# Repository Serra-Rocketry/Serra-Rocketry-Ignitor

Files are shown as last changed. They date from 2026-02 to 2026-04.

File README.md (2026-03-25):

# Serra Rocketry Ignitor




## Sobre
Sistema de ignição remota para foguetes experimentais da Serra Rocketry.

A solução é formada por duas estações independentes que se comunicam via LoRa 433 MHz:

1. Estação de Comando (operada pelo operador em distância segura)
2. Estação de Ignição (conectada fisicamente ao ignitor)

O objetivo é permitir ignição com redundância de segurança, confirmação de comunicação e feedback visual/sonoro durante toda a sequência.

## Arquitetura

### Estação de Comando
- Inicia a sequência de ignição por botão dedicado
- Exige ação mantida por 5 segundos
- Envia comando via LoRa e aguarda ACK
- Exibe status por LEDs e buzzer

### Estação de Ignição
- Recebe comando da estação de comando
- Executa contagem regressiva de 5 segundos
- Aborta se o comando for interrompido
- Aciona o ignitor ao fim da contagem

Para detalhes completos de pinagem, BOM, consumo, segurança e esquemáticos, consulte a documentação de hardware.

## Sequência de Ignição (Resumo)
1. Operador pressiona e mantém o botão de ignição por 5 s
2. Estação de comando envia `ARM` via LoRa
3. Estação de ignição confirma recebimento e inicia contagem
4. Se o botão for solto antes do fim, procedimento é abortado
5. Ao final de 5 s, a estação de ignição aciona o ignitor

## Componentes Principais
- 2x Raspberry Pi Pico
- 2x Módulos LoRa SX1278 (433 MHz)
- 2x LEDs amarelos e 2x LEDs vermelhos
- 2x Buzzers ativos
- 2x Botões liga/desliga
- 1x Botão de ignição momentâneo
- 1x Relé para acionamento do ignitor
- 2x Módulos TP4056 com proteção
- Baterias Li-ion/LiPo (capacidade em definição)
- Cases impressos em 3D

## Estrutura do Repositório
- `docs/`: documentação técnica e operacional
- `firmware/`: código embarcado e interface web local
- `hardware/`: esquemáticos, modelos, imagens e arquivos de fabricação
- `software/`: ferramentas de apoio de software
- `test/`: materiais de teste e validação

## Documentação
- [Hardware: arquitetura, BOM e pinagem](./hardware/README.md)
- [Instalação](./docs/INSTALACAO.md)
- [API e protocolos](./docs/API.md)
- [Testes](./docs/TESTES.md)
- [Troubleshooting](./docs/TROUBLESHOOTING.md)

## Segurança
- O botão de ignição deve ser momentâneo (sem trava)
- O comando de ignição deve permanecer ativo por toda a janela de 5 s
- Em perda de comunicação/heartbeat, o sistema deve abortar
- Testes devem ser feitos com carga dummy antes de ignição real
- Manter distância operacional segura entre operador e foguete

## Status do Projeto
- [x] Arquitetura macro de duas estações definida
- [x] BOM e pinagem iniciais documentados
- [ ] Firmware de comando e ignição finalizado
- [ ] Validação completa de comunicação LoRa
- [ ] Validação elétrica em bancada e campo
- [ ] Cases 3D finalizados para produção

## Contribuição
Consulte as diretrizes em [Boas Práticas Serra Rocketry](https://github.com/Serra-Rocketry/best-practices).

## Equipe
Projeto desenvolvido pela equipe Serra Rocketry.

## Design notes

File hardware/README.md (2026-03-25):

# Hardware - Serra Rocketry Ignitor

## Arquitetura do Sistema

O sistema é composto por **duas estações independentes** que se comunicam via rádio LoRa:

### 1. Estação de Comando
Operada remotamente pelo operador (distância segura do foguete).

**Função:**
- Iniciar sequência de ignição via botão dedicado
- Monitorar status da Estação de Ignição
- Fornecer feedback visual e sonoro ao operador

**Componentes:**
- 1x Raspberry Pi Pico
- 1x Módulo LoRa SX1278 433 MHz
- 1x Botão liga/desliga
- 1x Botão de ignição (ação mantida por 5 s)
- 2x LEDs: amarelo (conectado), vermelho (ignição iminente)
- 1x Buzzer ativo
- 1x Módulo TP4056 (com proteção) para recarregar a bateria
- 1x Bateria (a definir capacidade)
- Case impresso em 3D

### 2. Estação de Ignição
Conectada fisicamente ao ignitor do foguete.

**Função:**
- Receber comandos de ignição da Estação de Comando
- Executar contagem regressiva (5 s) com avisos sonoros
- Acionar o ignitor ao final da contagem
- Abortar procedimento se comando for interrompido

**Componentes:**
- 1x Raspberry Pi Pico
- 1x Módulo LoRa SX1278 433 MHz
- 2x LEDs: amarelo (conectado), vermelho (ignição iminente)
- 1x Buzzer ativo
- 1x Relé para acionamento do ignitor
- 1x Módulo TP4056 (com proteção) para recarregar a bateria
- 1x Bateria (a definir capacidade)
- Case impresso em 3D

## Lista de Componentes (BOM)

| Componente | Quantidade | Referência | Especificação | Link |
|---|---|---|---|---|
| Raspberry Pi Pico | 2 | MCU1, MCU2 | RP2040 | [Raspberry Pi](https://www.raspberrypi.com/products/raspberry-pi-pico/) |
| Módulo LoRa SX1278 | 2 | LORA1, LORA2 | 433 MHz | [Hoperf](https://www.hoperf.com/) |
| LED Amarelo 5mm | 2 | LED_Y1, LED_Y2 | 20 mA | - |
| LED Vermelho 5mm | 2 | LED_R1, LED_R2 | 20 mA | - |
| Buzzer ativo 5V | 2 | BZ1, BZ2 | Piezo | - |
| Botão Liga/Desliga | 2 | BTN_PWR1, BTN_PWR2 | 12V 20A | - |
| Botão de Ignição | 1 | BTN_IGN | 22mm, 3-9V (5V), Momentary Reset, Vermelho | - |
| Relé | 1 | K1 | Para ignitor (corrente a definir) | - |
| Bateria | 12 | BAT1, BAT2 | A definir (LiPo/18650) | - |
| Resistores 220Ω | 4 | R1-R4 | Para LEDs | - |
| Antena LoRa | 2 | ANT1, ANT2 | 433 MHz | - |
| Módulo TP4056 | 2 | CHG1, CHG2 | Carregador Li-ion/LiPo 1 célula (4,2 V), entrada 5 V, corrente de carga ajustável (até 1 A), proteção recomendada (DW01A+8205A) | - |

## Pinagem Raspberry Pi Pico

### Estação de Comando
| GPIO Pico | Conexão | Descrição |
|---|---|---|
| GP0 | LoRa SPI RX | SPI MISO |
| GP1 | LoRa SPI CS | Chip Select |
| GP2 | LoRa SPI SCK | SPI Clock |
| GP3 | LoRa SPI TX | SPI MOSI |
| GP4 | LoRa RESET | Reset |
| GP11 | LED Amarelo | Status: conectado |
| GP12 | LED Vermelho | Status: ignição iminente |
| GP13 | LED do botão | Status: ligado |
| GP19 | Buzzer | Alerta sonoro |
| GP14 | Botão Power | Liga/desliga |
| GP26 | Botão Ignição | Comando de ignição (segurar 5 s) |

### Estação de Ignição
| GPIO Pico | Conexão | Descrição |
|---|---|---|
| GP0 | LoRa SPI RX | SPI MISO |
| GP1 | LoRa SPI CS | Chip Select |
| GP2 | LoRa SPI SCK | SPI Clock |
| GP3 | LoRa SPI TX | SPI MOSI |
| GP4 | LoRa RESET | Reset |
| GP11 | LED Amarelo | Status: conectado com comando |
| GP12 | LED Vermelho | Status: ignição iminente |
| GP19 | Buzzer | Contagem regressiva |
| GP26 | Gate Ignitor | Comando Relé |

## Sequência de Operação

### Estados dos LEDs
| Estado | LED Amarelo | LED Vermelho |
|---|---|---|
| Desligado | OFF | OFF |
| Ligado (idle) | OFF | OFF |
| Conectado | ON | OFF |
| Ignição iminente | ON | PISCA |
| Ignição ativa | ON | ON |
| Erro | OFF | PISCA |

### Sequência de Ignição

1. **Operador pressiona botão de ignição na Estação de Comando**
   - Botão deve ser **mantido pressionado por 5 segundos**
   - LED vermelho começa a piscar
   - Buzzer emite tom contínuo

2. **Estação de Comando envia sinal LoRa para Estação de Ignição**
   - Pacote com comando `ARM`
   - Requer confirmação (ACK) da Estação de Ignição

3. **Estação de Ignição recebe comando e inicia contagem**
   - LED vermelho pisca rapidamente
   - Buzzer emite **5 apitos** (1 por segundo) = contagem regressiva
   - A cada segundo, verifica se comando ainda está ativo

4. **Durante a contagem (5 s):**
   - Se botão na Estação de Comando for **solto**: abortado
   - Estação de Ignição envia mensagem de abort
   - Ambas as estações voltam ao estado "Conectado"

5. **Ao final dos 5 segundos:**
   - LED vermelho fica **sólido** em ambas estações
   - Estação de Ignição aciona o ignitor (GPIO16 HIGH)
   - Buzzer emite tom longo de confirmação

6. **Após ignição:**
   - Sistema aguarda 3 s e retorna ao estado "Conectado"

## Segurança

- Botão de ignição deve ser do tipo **momentâneo** (não trava)
- Ignição só ocorre se comando for mantido por toda a sequência (5 s)
- Comunicação LoRa bidirecional: Estação de Ignição confirma recebimento
- Timeout: se Estação de Ignição não receber heartbeat por 2 s, aborta
- Sensor de continuidade (opcional): verifica se ignitor está conectado antes de armar

## Consumo de Energia

**Estimativas iniciais (a validar):**
- Operação normal (conectado): ~50 mA @ 3.3 V
- Transmissão LoRa: ~120 mA (picos)
- Autonomia estimada: 6-8 h com bateria 1000 mAh

### Carregamento com TP4056

- Cada estação usa um TP4056 dedicado (CHG1 e CHG2) para 2 células Li-ion/LiPo (3,7 V nominal).
- Conexão típica: `IN+ / IN-` (5 V da porta USB), `BAT+ / BAT-` (bateria), `OUT+ / OUT-` (alimentação da carga) quando a placa tiver proteção integrada.
- Corrente de carga recomendada para bateria de 1000 mAh: 0,5 A a 1,0 A (0,5C a 1C), respeitando especificação da bateria.
- Preferir módulos com proteção (DW01A + 8205A) para reduzir risco de sobrecarga, descarga profunda e curto.

## Galeria de Componentes

### Raspberry Pi Pico
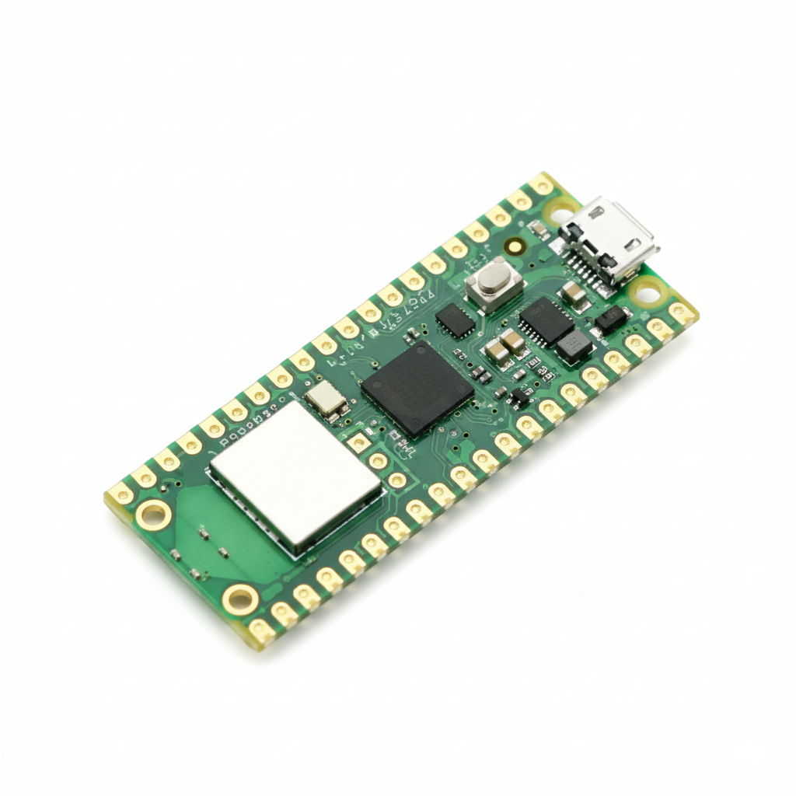
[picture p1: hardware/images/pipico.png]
Raspberry Pi Pico


Microcontrolador dual-core ARM Cortex-M0+ (RP2040), 264KB SRAM, 2MB Flash.

### Módulo LoRa SX1268
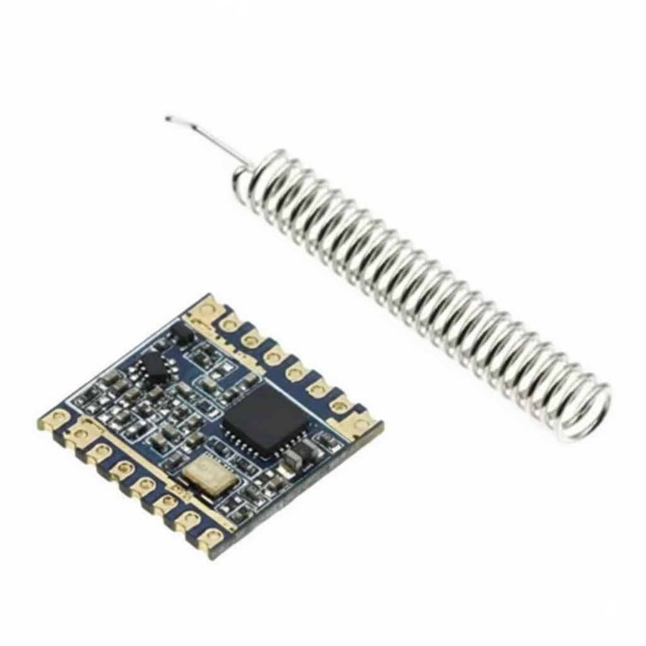
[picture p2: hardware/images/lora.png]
Módulo LoRa SX1268


Transceptor LoRa de longo alcance operando em **433 MHz**. Chip Semtech SX1268.

### Botão Liga/Desliga
Botão Liga/Desliga

Botão de potência **12V 20A** para controle de energia das estações.

### Botão de Ignição

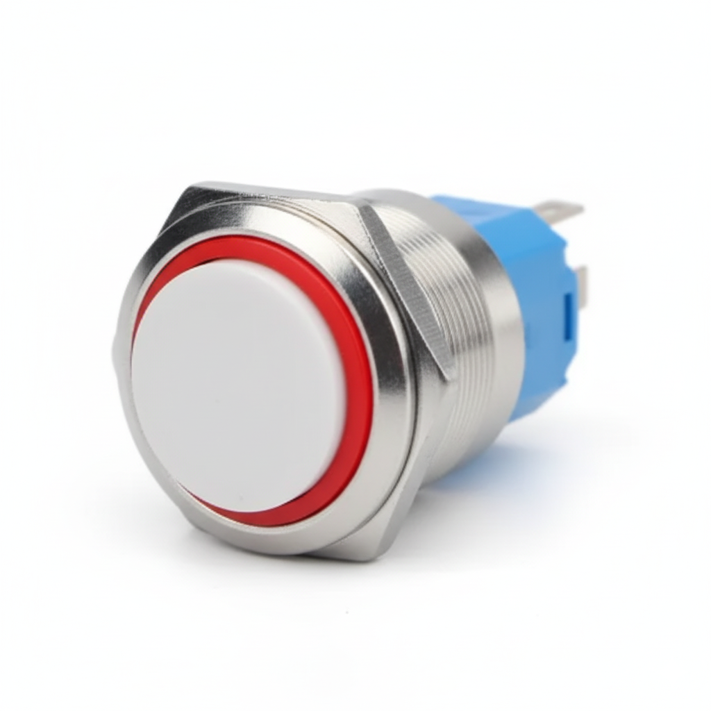
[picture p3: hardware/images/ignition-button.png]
Botão de Ignição


Botão momentâneo (Momentary Reset), **22mm**, vermelho, **3-9V (5V)**. Usado exclusivamente na Estação de Comando para iniciar a sequência de ignição.

## Esquemáticos

### Estação de comando

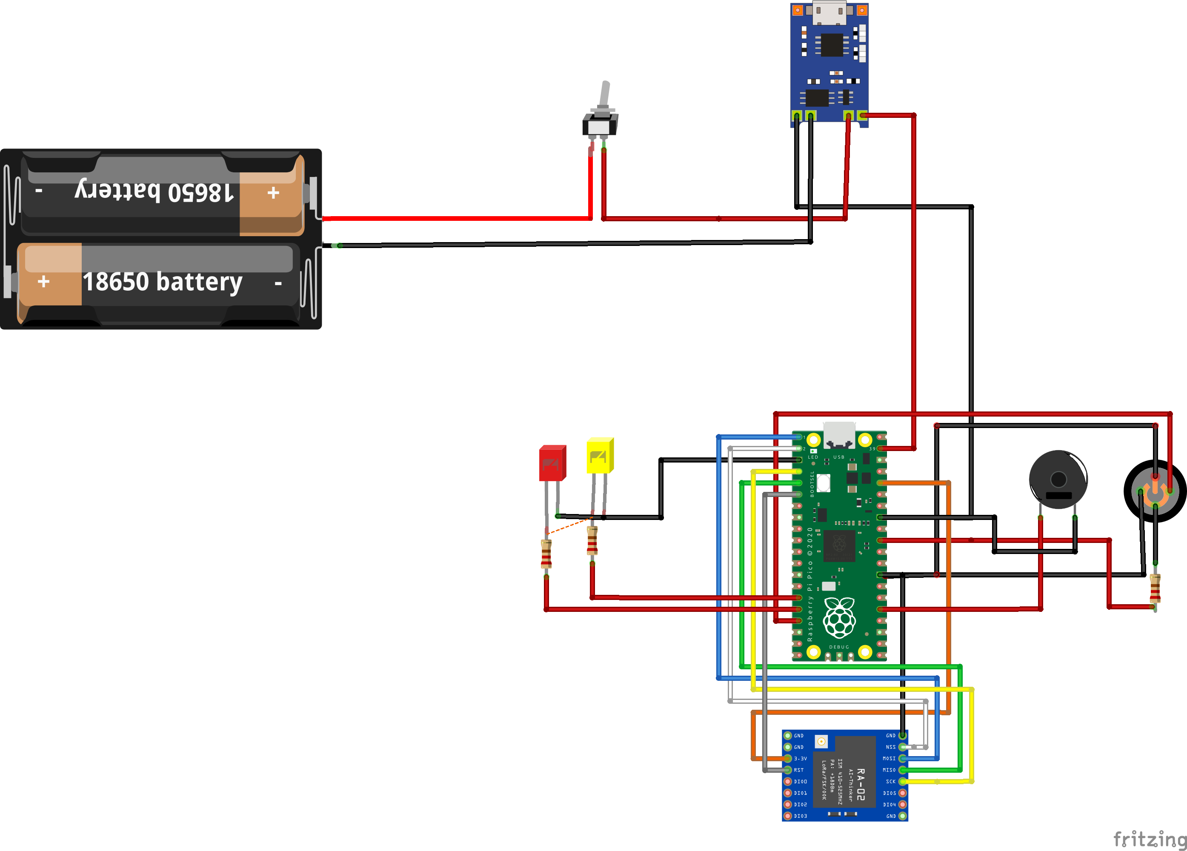
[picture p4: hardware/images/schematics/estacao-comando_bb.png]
Esquemático fritzing, caixa de comando


### Estação de ignicão

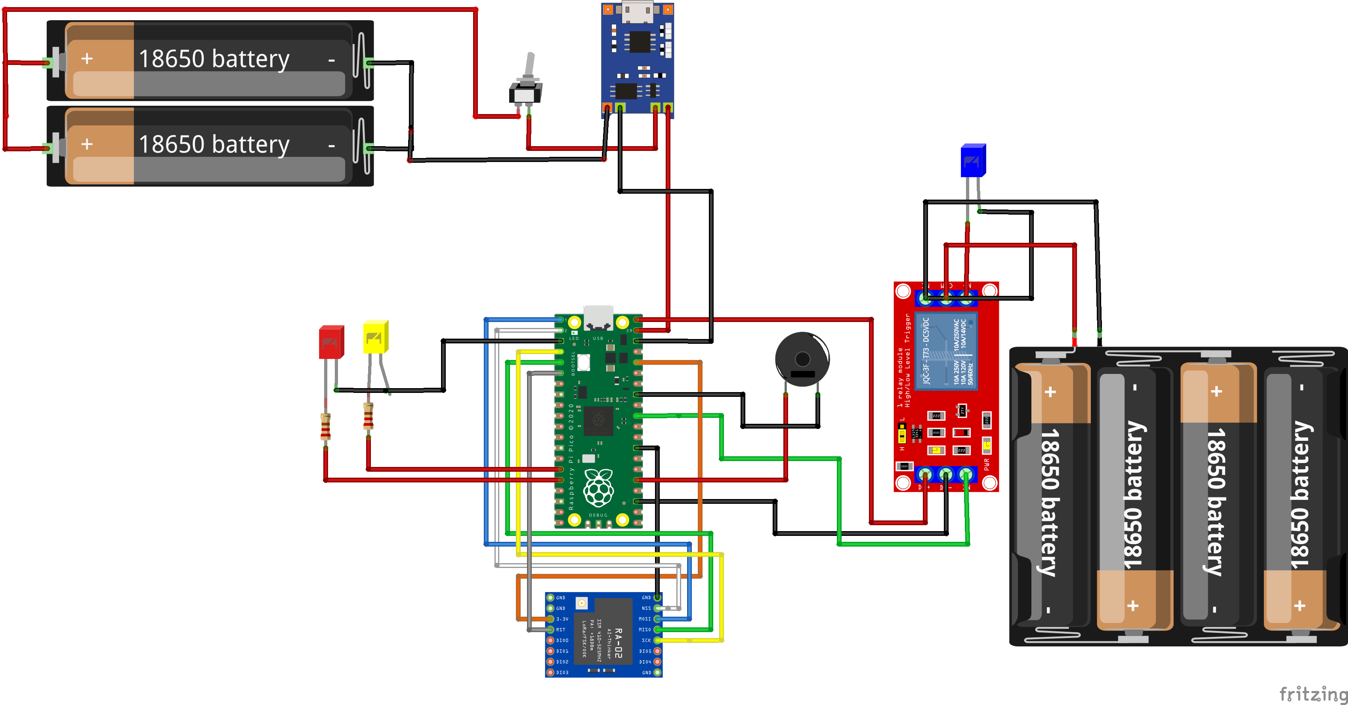
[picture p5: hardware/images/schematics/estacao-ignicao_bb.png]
Esquemático fritzing, caixa de ignição


## Arquivos de Fabricação

- [Modelos 3D dos cases](./3d_models/) - *A criar*

## Notas Importantes

- **Sempre conectar antena LoRa antes de energizar** (dano ao módulo)
- Isolar circuito do ignitor via relé
- Testar sequência completa com carga dummy (lâmpada) antes de uso real
- Manter distância mínima de 10 m entre operador e foguete

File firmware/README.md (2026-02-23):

# Firmware - Serra Rocketry Ignitor

## Visão Geral

O firmware é desenvolvido em **MicroPython** para Raspberry Pi Pico. Existem dois programas principais:
- `command_station.py` - Firmware da Estação de Comando
- `ignition_station.py` - Firmware da Estação de Ignição

## Arquitetura

### Estação de Comando

**Máquina de Estados:**
1. **IDLE** - Sistema ligado, aguardando conexão
2. **CONNECTED** - Heartbeat estabelecido com Estação de Ignição
3. **ARMING** - Botão de ignição pressionado, enviando comandos ARM
4. **IGNITION** - Ignição confirmada pela Estação de Ignição
5. **ERROR** - Erro de comunicação ou timeout

**Responsabilidades:**
- Enviar `HEARTBEAT` a cada 1 s
- Monitorar botão de ignição (GP15)
- Enviar sequência `ARM_ACTIVE` com contadores 5→0
- Enviar `ABORT` se botão for solto prematuramente
- Atualizar LEDs e buzzer conforme estado

### Estação de Ignição

**Máquina de Estados:**
1. **IDLE** - Sistema ligado, aguardando conexão
2. **CONNECTED** - Recebendo heartbeats da Estação de Comando
3. **ARMED** - Recebendo comandos ARM, executando contagem regressiva
4. **IGNITION** - Acionando ignitor (GP16 HIGH)
5. **ERROR** - Timeout de comunicação ou falha de hardware

**Responsabilidades:**
- Responder `HEARTBEAT_ACK` aos heartbeats
- Validar sequência de comandos `ARM_ACTIVE`
- Executar contagem regressiva com apitos
- Acionar ignitor (GP16) ao receber `ARM_ACTIVE(0)`
- Abortar se não receber heartbeat por 2 s

## Configuração

### 1. Copiar Template

```bash
cp firmware/config.example.h firmware/config.h
```

### 2. Ajustar Parâmetros

Editar `config.h`:

```python
# Identificação da estação
STATION_TYPE = "COMMAND"  # ou "IGNITION"
STATION_ID = 0x01

# LoRa
LORA_FREQ = 915.0  # MHz
LORA_BANDWIDTH = 125000  # Hz
LORA_SPREADING_FACTOR = 7  # 7-12 (maior = mais alcance, menor velocidade)
LORA_TX_POWER = 20  # dBm

# Timeouts
HEARTBEAT_INTERVAL = 1.0  # segundos
HEARTBEAT_TIMEOUT = 2.0   # segundos
ARM_INTERVAL = 1.0        # segundos (1 por segundo na contagem)

# GPIOs
PIN_LED_GREEN = 10
PIN_LED_YELLOW = 11
PIN_LED_RED = 12
PIN_BUZZER = 13
PIN_BUTTON_POWER = 14
PIN_BUTTON_IGNITION = 15  # apenas Estação de Comando
PIN_IGNITOR_GATE = 16     # apenas Estação de Ignição
```

## Estrutura do Código

```
firmware/
├── config.example.h       # Template de configuração
├── config.h               # Configuração local (gitignored)
├── lib/
│   ├── lora.py           # Driver LoRa (SX1276/SX1278)
│   ├── protocol.py       # Codificação/decodificação de pacotes
│   └── state_machine.py  # Lógica de estados
├── command_station.py     # Firmware Estação de Comando
└── ignition_station.py    # Firmware Estação de Ignição
```

## Fluxo de Dados

### Estação de Comando

```
main loop (100 Hz):
  1. Ler botão de ignição (GP15)
  2. Se pressionado e CONNECTED:
       - Entrar em ARMING
       - Enviar ARM_ACTIVE(counter)
       - Decrementar counter a cada 1 s
  3. Se solto durante ARMING:
       - Enviar ABORT
       - Voltar para CONNECTED
  4. A cada 1 s:
       - Enviar HEARTBEAT
       - Atualizar LEDs conforme estado
  5. Processar respostas do LoRa
```

### Estação de Ignição

```
main loop (100 Hz):
  1. Receber pacotes LoRa
  2. Se HEARTBEAT recebido:
       - Responder HEARTBEAT_ACK
       - Resetar timer de timeout
  3. Se ARM_ACTIVE recebido:
       - Validar contador sequencial
       - Emitir apito do buzzer
       - Atualizar LED vermelho (piscar)
  4. Se ARM_ACTIVE(0) recebido:
       - Acionar GP16 HIGH (ignitor)
       - LED vermelho sólido
       - Buzzer tom longo
  5. Se timeout (2 s sem HEARTBEAT):
       - Abortar, entrar em ERROR
       - LED vermelho pisca rápido
  6. Atualizar LEDs/buzzer conforme estado
```

## Comandos e Protocolos

Ver documentação completa em `docs/API.md`.

**Mensagens principais:**
- `HEARTBEAT` (0x10) - Comando → Ignição
- `HEARTBEAT_ACK` (0x11) - Ignição → Comando
- `ARM_ACTIVE(N)` (0x21) - Comando → Ignição, N = 5..0
- `ABORT` (0x22) - Comando → Ignição
- `STATUS_ARMED(N)` (0x42) - Ignição → Comando

## Build e Deploy

### Usando Thonny IDE

1. Conectar Raspberry Pi Pico via USB (segurar BOOTSEL)
2. Instalar MicroPython via Thonny (Tools → Options → Interpreter)
3. Carregar bibliotecas:
   - File → Save as → Raspberry Pi Pico → `lib/lora.py`
   - Repetir para `protocol.py` e `state_machine.py`
4. Carregar firmware principal:
   - Abrir `command_station.py` (ou `ignition_station.py`)
   - File → Save as → Raspberry Pi Pico → `main.py`
5. Desconectar e reconectar Pico (sem BOOTSEL) - deve executar automaticamente

### Usando ampy (linha de comando)

```bash
# Instalar ampy
pip install adafruit-ampy

# Upload de bibliotecas
ampy --port /dev/ttyACM0 mkdir lib
ampy --port /dev/ttyACM0 put lib/lora.py lib/lora.py
ampy --port /dev/ttyACM0 put lib/protocol.py lib/protocol.py
ampy --port /dev/ttyACM0 put lib/state_machine.py lib/state_machine.py

# Upload firmware (Estação de Comando)
ampy --port /dev/ttyACM0 put command_station.py main.py

# Upload firmware (Estação de Ignição)
ampy --port /dev/ttyACM1 put ignition_station.py main.py
```

## Debug via Serial

Conectar monitor serial (115200 baud) para ver logs:

```bash
screen /dev/ttyACM0 115200
# ou
minicom -D /dev/ttyACM0 -b 115200
```

**Mensagens esperadas:**
```
[COMMAND] Boot OK
[COMMAND] LoRa init: 915.0 MHz
[COMMAND] State: IDLE
[COMMAND] -> HEARTBEAT
[COMMAND] <- HEARTBEAT_ACK (RSSI: -45)
[COMMAND] State: CONNECTED
[COMMAND] Button pressed, starting ARM
[COMMAND] -> ARM_ACTIVE(5)
[COMMAND] <- STATUS_ARMED(5)
...
[COMMAND] -> ARM_ACTIVE(0)
[COMMAND] <- STATUS_IGNITION
[COMMAND] State: IGNITION
```

## Testes

### Teste Unitário (sem hardware)

```bash
cd firmware
python -m pytest tests/
```

### Teste de Integração (com hardware)

Ver `test/README.md` para procedimentos completos.

## Segurança no Código

- **Watchdog timer:** Reinicia Pico se main loop travar
- **Validação de CRC:** Todo pacote LoRa é verificado antes de processar
- **Timeout rígido:** Estação de Ignição aborta se não receber heartbeat por 2 s
- **Sequência monotônica:** Contador ARM_ACTIVE deve ser decrescente e sequencial (5→4→3→2→1→0)

## Próximas Implementações

- [ ] Criptografia AES-128 nos pacotes LoRa
- [ ] Sensor de continuidade do ignitor (GP17)
- [ ] Log em flash interno (últimas 10 ignições)
- [ ] Modo de diagnóstico via serial
- [ ] Over-the-air (OTA) update via LoRa

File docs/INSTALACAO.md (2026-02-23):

# Guia de Instalação Detalhado

## Visão Geral

Este guia orienta a montagem das duas estações do sistema de ignição:
- **Estação de Comando** (operada remotamente)
- **Estação de Ignição** (conectada ao foguete)

## 1. Pré-requisitos de Ambiente

### Software
- Python 3.8+ (`pip install -r requirements.txt`)
- Thonny IDE (recomendado para Raspberry Pi Pico) ou VS Code com extensão MicroPython
- Ferramenta de flash: `picotool` ou via Thonny

### Hardware
- Multímetro para verificação de continuidade
- Fonte de bancada 3.3-5 V ou baterias
- Ferro de solda (montagem em protoboard ou PCB)

## 2. Clonar e Preparar

```bash
git clone https://github.com/Serra-Rocketry/Serra-Rocketry-Ignitor.git
cd Serra-Rocketry-Ignitor
pip install -r requirements.txt
```

## 3. Montagem de Hardware

### 3.1. Estação de Comando

**Componentes necessários:**
- 1x Raspberry Pi Pico
- 1x Módulo LoRa 915 MHz
- 3x LEDs (verde, amarelo, vermelho) + 3x resistores 220Ω
- 1x Buzzer ativo 5V
- 2x Botões tácteis (power, ignição)
- Bateria e regulador (se necessário)

**Conexões:** Ver pinagem detalhada em `hardware/README.md`.

**Checklist:**
1. Soldar headers no Raspberry Pi Pico (se necessário)
2. Conectar módulo LoRa via SPI (GP0-GP4)
3. Conectar LEDs aos GPIOs 10-12 com resistores
4. Conectar buzzer ao GP13
5. Conectar botões aos GP14 (power) e GP15 (ignição) com pull-down
6. Fixar antena no módulo LoRa **antes** de energizar
7. Conectar bateria/fonte

### 3.2. Estação de Ignição

**Componentes necessários:**
- 1x Raspberry Pi Pico
- 1x Módulo LoRa 915 MHz
- 3x LEDs (verde, amarelo, vermelho) + 3x resistores 220Ω
- 1x Buzzer ativo 5V
- 1x MOSFET ou relé para ignitor
- Bateria e regulador (se necessário)

**Conexões:** Ver pinagem detalhada em `hardware/README.md`.

**Checklist:**
1. Soldar headers no Raspberry Pi Pico
2. Conectar módulo LoRa via SPI (GP0-GP4)
3. Conectar LEDs aos GPIOs 10-12 com resistores
4. Conectar buzzer ao GP13
5. Conectar MOSFET/relé ao GP16 (gate do ignitor)
6. Isolar circuito do ignitor com diodo flyback (se usar relé)
7. Fixar antena no módulo LoRa **antes** de energizar
8. Conectar bateria/fonte

### 3.3. Teste de Continuidade

Antes de energizar:
- Verificar curto-circuitos com multímetro
- Confirmar polaridade da bateria
- Verificar que antenas estão conectadas

## 4. Configuração do Firmware

### 4.1. Copiar Configuração

```bash
cp firmware/config.example.h firmware/config.h
```

Editar `config.h` e ajustar:
- `LORA_FREQ` → 915.0 (MHz)
- `STATION_TYPE` → `COMMAND` ou `IGNITION`
- IDs únicos para cada estação

### 4.2. Compilar e Gravar

#### Usando Thonny:
1. Abrir Thonny IDE
2. Conectar Raspberry Pi Pico via USB (segurar BOOTSEL ao conectar)
3. Instalar MicroPython: Tools → Options → Interpreter → Install or update MicroPython
4. Abrir `firmware/main.py` (Estação de Comando ou Ignição)
5. Clicar em Run → Save to Raspberry Pi Pico
6. Repetir para a outra estação

#### Usando linha de comando:
```bash
cd firmware
# Para Estação de Comando
ampy --port /dev/ttyACM0 put command_station.py main.py

# Para Estação de Ignição
ampy --port /dev/ttyACM1 put ignition_station.py main.py
```

## 5. Validar Operação

### 5.1. Teste Inicial (sem ignitor)

1. Energizar **apenas** a Estação de Comando
   - LED verde deve acender
   - LED amarelo permanece apagado (sem conexão)

2. Energizar a Estação de Ignição
   - LED verde acende em ambas
   - Após 1-2 s, LEDs amarelos acendem (heartbeat estabelecido)
   - Monitor serial mostra mensagens `HEARTBEAT` e `HEARTBEAT_ACK`

3. Testar sequência de ignição (com carga dummy)
   - Conectar LED/lâmpada ao GP16 da Estação de Ignição
   - Pressionar e segurar botão de ignição na Estação de Comando
   - Observar: LEDs vermelhos piscam, buzzer emite 5 apitos
   - Ao final, LED/lâmpada conectada ao GP16 acende

### 5.2. Teste de Abort

1. Iniciar sequência de ignição
2. Soltar botão após 2-3 segundos
3. Confirmar que carga dummy **não** aciona

### 5.3. Teste de Alcance

1. Posicionar estações a 50 m de distância (LOS)
2. Confirmar LEDs amarelos permanecem acesos
3. Executar sequência completa de ignição
4. Se sucesso, aumentar distância gradualmente

## 6. Montagem nos Cases 3D

1. Imprimir cases: `hardware/3d_models/case_command.stl` e `case_ignition.stl`
2. Fixar componentes com parafusos M3 ou cola quente
3. Garantir que antenas ficam externas ao case
4. Posicionar LEDs e botões nos furos frontais

## 7. Integração com Ignitor Real

⚠️ **ATENÇÃO: Realizar apenas em local seguro e com supervisão!**

1. Conectar ignitor aos terminais da Estação de Ignição (saída do MOSFET/relé)
2. Confirmar continuidade com multímetro
3. Posicionar Estação de Ignição junto ao foguete (≥ 10 m de distância)
4. Operador permanece com Estação de Comando em posição segura
5. Executar sequência de ignição conforme procedimento operacional

## 8. Troubleshooting Inicial

| Problema | Possível Causa | Solução |
|---|---|---|
| LED verde não acende | Sem alimentação | Verificar bateria/fonte |
| LED amarelo não acende | LoRa não comunica | Confirmar antenas, frequência, conexões SPI |
| Buzzer não soa | GPIO mal conectado | Verificar GP13, trocar buzzer |
| Ignitor não aciona | MOSFET/relé com problema | Testar GP16 com LED, verificar gate driver |

Ver mais em `docs/TROUBLESHOOTING.md`.

## 9. Próximos Passos

- Executar plano de testes completo: `test/README.md`
- Registrar resultados em `docs/TESTES.md`
- Calibrar alcance LoRa conforme necessidade
- Imprimir cases finais após validação

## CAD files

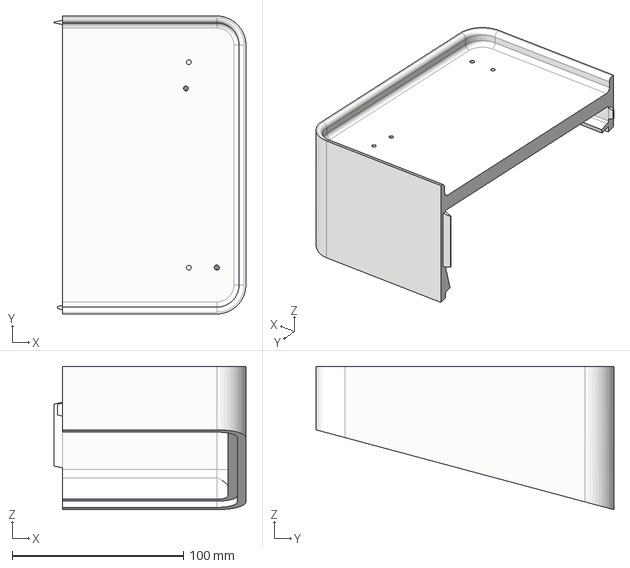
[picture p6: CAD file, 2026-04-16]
hardware/3d_models/comando/lado1.step
112.0 x 174.0 x 83.7 mm

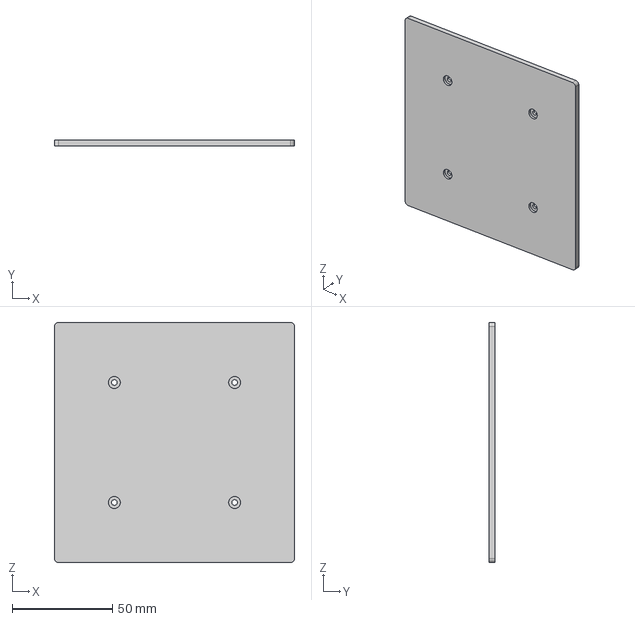
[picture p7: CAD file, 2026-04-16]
hardware/3d_models/ignição/TAMPABAIXO.step
120.0 x 3.00 x 120.0 mm

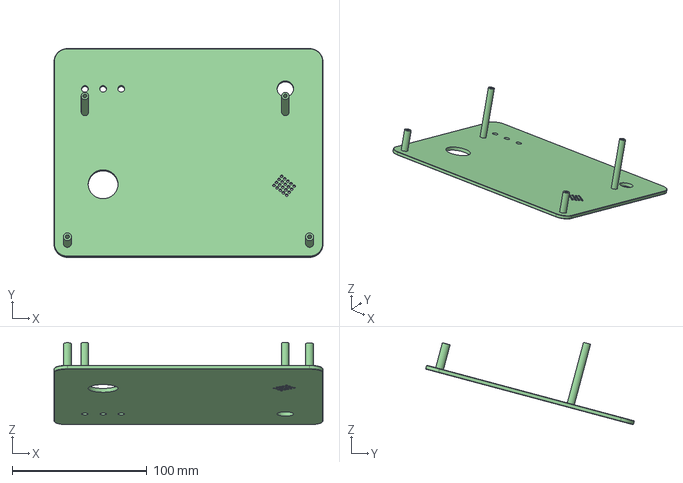
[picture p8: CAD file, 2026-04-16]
hardware/3d_models/comando/tampacima.step
200.0 x 155.2 x 61.2 mm
caixa
Componente3

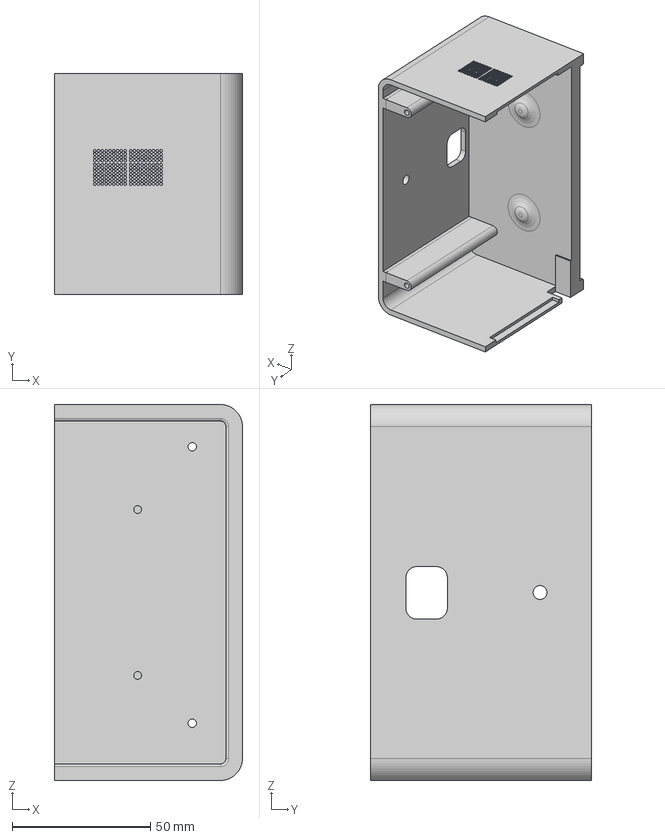
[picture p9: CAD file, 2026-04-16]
hardware/3d_models/ignição/caixapart2.step
68.0 x 80.0 x 136.0 mm

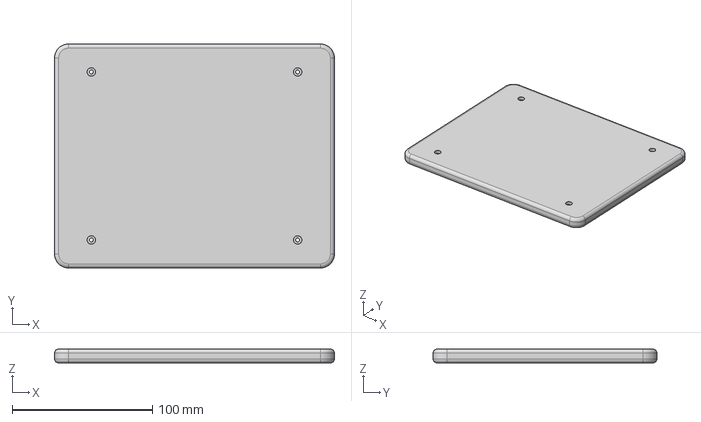
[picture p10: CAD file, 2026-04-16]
hardware/3d_models/comando/tampabaixo.step
200.0 x 160.0 x 10.0 mm

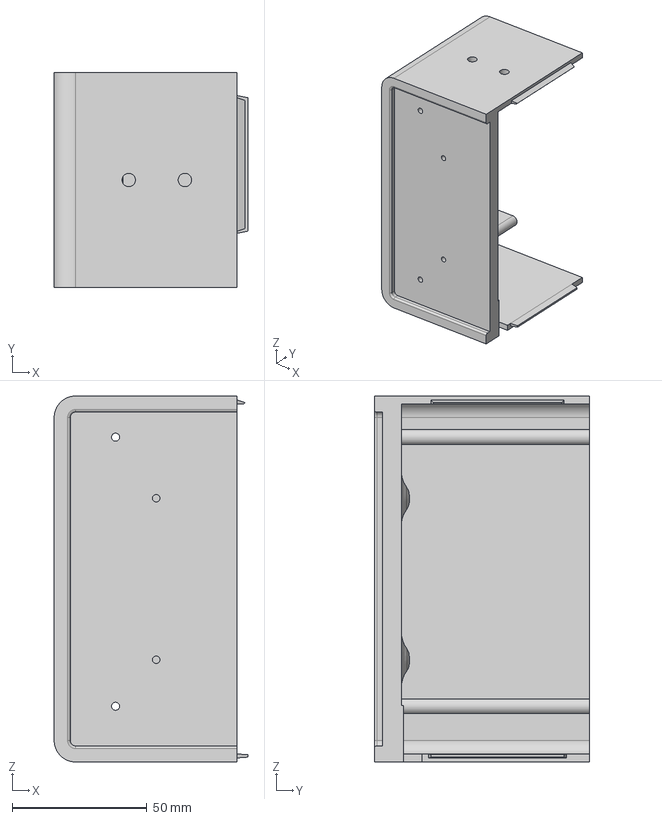
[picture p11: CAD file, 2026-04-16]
hardware/3d_models/ignição/caixapart1.step
72.0 x 80.0 x 136.0 mm

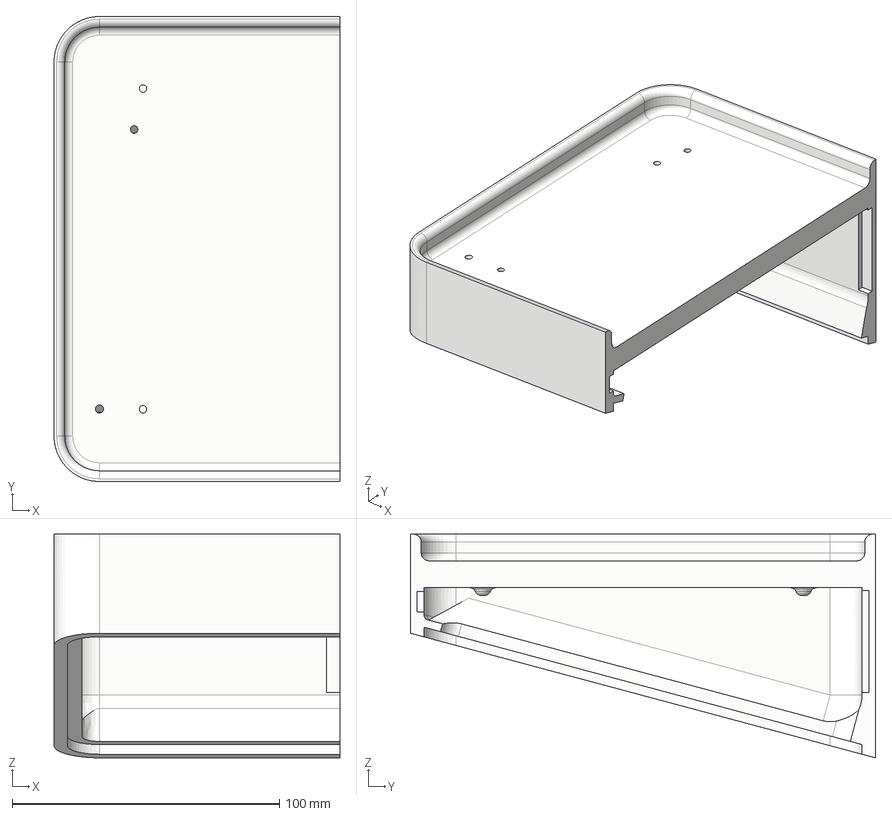
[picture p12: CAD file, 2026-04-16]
hardware/3d_models/comando/lado2.step
107.0 x 174.0 x 83.7 mm

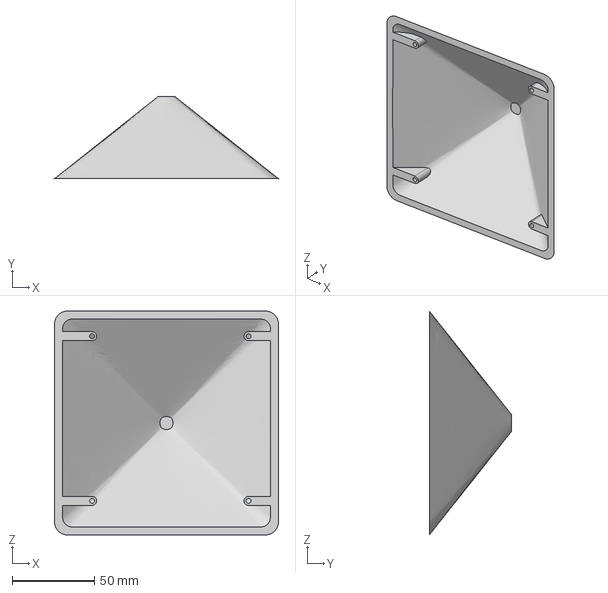
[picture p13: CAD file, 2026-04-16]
hardware/3d_models/ignição/TAMPACIMA.step
136.0 x 50.0 x 136.0 mm

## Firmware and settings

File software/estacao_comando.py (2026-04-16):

"""
╔══════════════════════════════════════════════════════════════════╗
║         ESTAÇÃO DE COMANDO — SISTEMA DE IGNIÇÃO LoRa             ║
║  Arquivo  : command_station.py                                   ║
║  Hardware : Raspberry Pi Pico + SX1278 (433 MHz)                 ║
║  Autor    : Sistema de Ignição de Foguetes                       ║
╚══════════════════════════════════════════════════════════════════╝

PINAGEM — SX1278 → Raspberry Pi Pico
─────────────────────────────────────
  SX1278   │ Pico GPIO │ Pino físico
  ─────────┼───────────┼────────────
  MOSI     │ GP3      │ 5
  MISO     │ GP0      │ 1
  SCK      │ GP2      │ 4
  NSS/CS   │ GP1      │ 2
  RESET    │ GP4      │ 6
  DIO0/G0  │ GP15      │ 20


PERIFÉRICOS
─────────────────────────────────────
  LED Amarelo → GP11  (pino 15)   + resistor 330Ω → GND
  LED Vermelho→ GP12  (pino 16)   + resistor 330Ω → GND
  Buzzer      → GP19  (pino 25)   + resistor 100Ω → GND
  Botão       → GP26  (pino 31)   → GND  (pull-up interno ativado)
"""

from machine import Pin, SPI
import utime

# ─────────────────────────────────────────────────────────────────
#  DEPENDÊNCIA: driver SX127x para MicroPython
#  Instale copiando sx127x.py para o Pico via Thonny ou mpremote.
#  Repositório: https://github.com/Serra-Rocketry/ignitor
#  ou instale via: mpremote mip install github:Wei1234c/SX127x_driver
# ─────────────────────────────────────────────────────────────────
try:
    from sx127x import SX127x
    LORA_AVAILABLE = True
except ImportError:
    # Modo de desenvolvimento sem hardware LoRa
    LORA_AVAILABLE = False
    print("[WARN] sx127x não encontrado — rodando sem LoRa real.")


# ╔══════════════════════════════════════════════════════════════╗
# ║                     CONFIGURAÇÕES                           ║
# ╚══════════════════════════════════════════════════════════════╝

# ── Pinos SPI / LoRa ─────────────────────────────────────────────
PIN_MOSI  = 5
PIN_MISO  = 1
PIN_SCK   = 4
PIN_CS    = 2
PIN_RESET = 6
PIN_DIO0  = 20

# ── Periféricos ──────────────────────────────────────────────────
PIN_LED_YELLOW = 15  # pisca durante o arme
PIN_LED_RED    = 16  # acende fixo ao receber ACK
PIN_BUZZER     = 25  # bipes de alerta
PIN_BUTTON     = 31  # botão momentâneo (active-low, pull-up)

# ── Tempos (ms) ──────────────────────────────────────────────────
HOLD_REQUIRED_MS   = 5_000   # tempo que o botão deve ficar pressionado
DEBOUNCE_MS        = 50      # janela de debounce
BLINK_INTERVAL_MS  = 250     # cadência do LED amarelo / buzzer
ACK_TIMEOUT_MS     = 2_000   # aguarda ACK por este tempo após ARM_CONFIRMED
RETRANSMIT_MS      = 200     # intervalo entre re-envios do ARM_CONFIRMED

# ── Mensagens LoRa ───────────────────────────────────────────────
MSG_ARM    = "ARM_CONFIRMED"
MSG_ABORT  = "ABORT"
MSG_ACK    = "ACK"

# ── Parâmetros LoRa (SX1278 @ 433 MHz) ──────────────────────────
LORA_PARAMS = {
    "frequency"         : 433e6,
    "bandwidth"         : 125e3,
    "spreading_factor"  : 7,
    "coding_rate"       : 5,        # 4/5
    "output_power"      : 17,       # dBm (máx 20)
    "rx_crc"            : True,
}


# ╔══════════════════════════════════════════════════════════════╗
# ║                    ESTADOS DA MÁQUINA                       ║
# ╚══════════════════════════════════════════════════════════════╝
class State:
    # Estado inicial: aguardando a pressão do botão de ignição.
    IDLE        = "IDLE"
    # Estado de armamento: o botão está pressionado e o sistema conta 5 segundos.
    ARMING      = "ARMING"
    # Estado de transmissão: envia repetidamente o comando de armamento.
    TRANSMITTING = "TRANSMITTING"
    # Estado de confirmação: ACK recebido do receptor, ignição confirmada.
    CONFIRMED   = "CONFIRMED"
    # Estado de aborto: envia ABORT para o receptor e retorna a IDLE.
    ABORTING    = "ABORTING"


# ╔══════════════════════════════════════════════════════════════╗
# ║                  DRIVER LoRa (wrapper)                      ║
# ╚══════════════════════════════════════════════════════════════╝
class LoRaRadio:
    """
    Abstração sobre o driver SX127x.

    Permite operar com o rádio real quando o driver está instalado e
    um modo mock silencioso quando o hardware não está disponível.
    """

    def __init__(self):
        if LORA_AVAILABLE:
            spi = SPI( 
                1,
                baudrate=1_000_000,
                polarity=0,
                phase=0,
                sck=Pin(PIN_SCK),
                mosi=Pin(PIN_MOSI),
                miso=Pin(PIN_MISO),
            )
            self._lora = SX127x(
                spi,
                pins={
                    "cs"    : Pin(PIN_CS,    Pin.OUT),
                    "reset" : Pin(PIN_RESET, Pin.OUT),
                    "dio0"  : Pin(PIN_DIO0,  Pin.IN),
                },
                parameters=LORA_PARAMS,
            )
            print("[LoRa] SX1278 inicializado em 433 MHz.")
        else:
            self._lora = None
            print("[LoRa] Modo MOCK ativo.")

    def send(self, message: str) -> None:
        """Transmite uma mensagem pela interface LoRa e mostra log local."""
        if self._lora:
            self._lora.println(message)
        print(f"[LoRa TX] → {message}")

    def receive(self) -> str | None:
        """
        Lê um pacote LoRa não bloqueante, se houver.

        Retorna a mensagem decodificada ou None quando não há nenhum pacote.
        """
        if self._lora and self._lora.received_packet():
            payload = self._lora.read_payload(with_header=False)
            msg = bytes(payload).decode("utf-8", "ignore").strip()
            print(f"[LoRa RX] ← {msg}")
            return msg
        return None


# ╔══════════════════════════════════════════════════════════════╗
# ║                 ESTAÇÃO DE COMANDO                          ║
# ╚══════════════════════════════════════════════════════════════╝
class CommandStation:
    """
    Máquina de estados para a estação de comando.

    Esta classe controla o ciclo de armamento e transmissão de mensagens
    de ignição via LoRa, usando um botão físico e indicadores visuais.

    Fluxo de estados:
    IDLE -> ARMING -> TRANSMITTING -> CONFIRMED -> IDLE
    """

    def __init__(self):
        # Inicializa os componentes físicos e o rádio LoRa.
        self.led_yellow = Pin(PIN_LED_YELLOW, Pin.OUT, value=0)
        self.led_red    = Pin(PIN_LED_RED,    Pin.OUT, value=0)
        self.buzzer     = Pin(PIN_BUZZER,     Pin.OUT, value=0)
        self.button     = Pin(PIN_BUTTON,     Pin.IN,  Pin.PULL_UP)
        self.lora       = LoRaRadio()

        # Estado atual da máquina e estado anterior reservado para futura expansão.
        self.state       = State.IDLE
        self._prev_state = None

        # Tempos de controle usados para armamento, piscar e transmissão.
        self._press_start_ms  = 0    # instante em que o botão foi pressionado
        self._last_blink_ms   = 0    # instante do último piscar do LED/buzzer
        self._last_tx_ms      = 0    # instante do último envio de ARM_CONFIRMED
        self._tx_start_ms     = 0    # instante do início da fase de transmissão

        # Debounce do botão para evitar leituras falsas.
        self._last_btn_change_ms = 0
        self._btn_stable_state   = True   # True significa botão solto (pull-up ativo)

        # Estado de toggle para o efeito de piscar.
        self._blink_on = False

    # ─────────────────────────────────────────
    #  LEITURA COM DEBOUNCE
    # ─────────────────────────────────────────
    def _button_pressed(self) -> bool:
        """
        Retorna True se o botão está estável e pressionado.
        Implementa debounce por tempo: só atualiza o estado estável
        após DEBOUNCE_MS ms de sinal constante.
        """
        raw = self.button.value() == 0   # active-low
        now = utime.ticks_ms()

        if raw != self._btn_stable_state:
            if utime.ticks_diff(now, self._last_btn_change_ms) >= DEBOUNCE_MS:
                self._btn_stable_state   = raw
                self._last_btn_change_ms = now

        return self._btn_stable_state

    # ─────────────────────────────────────────
    #  CONTROLE DE SAÍDAS
    # ─────────────────────────────────────────
    def _all_off(self):
        """Desliga todos os indicadores visuais e sonoros."""
        self.led_yellow.value(0)
        self.led_red.value(0)
        self.buzzer.value(0)
        self._blink_on = False

    def _blink_tick(self):
        """Alterna LED amarelo e buzzer em BLINK_INTERVAL_MS."""
        now = utime.ticks_ms()
        if utime.ticks_diff(now, self._last_blink_ms) >= BLINK_INTERVAL_MS:
            self._last_blink_ms = now
            self._blink_on = not self._blink_on
            self.led_yellow.value(self._blink_on)
            self.buzzer.value(self._blink_on)

    # ─────────────────────────────────────────
    #  TRANSIÇÕES DE ESTADO
    # ─────────────────────────────────────────
    def _enter_idle(self):
        self._all_off()
        self.state = State.IDLE
        print("[CMD] Estado: IDLE — aguardando botão.")

    def _enter_arming(self): 
        self._press_start_ms = utime.ticks_ms()
        self._last_blink_ms  = self._press_start_ms
        self.state = State.ARMING
        print("[CMD] Estado: ARMING — mantenha o botão por 5 s...")

    def _enter_transmitting(self):
        self._tx_start_ms = utime.ticks_ms()
        self._last_tx_ms  = 0
        self.state = State.TRANSMITTING
        print("[CMD] Estado: TRANSMITTING — enviando ARM_CONFIRMED.")

    def _enter_confirmed(self):
        self._all_off()
        self.led_red.value(1)    # LED vermelho fixo = ACK recebido
        self.state = State.CONFIRMED
        print("[CMD] Estado: CONFIRMED — ACK recebido! LED vermelho aceso.")

    def _enter_aborting(self):
        self.lora.send(MSG_ABORT)
        self._all_off()
        self.state = State.ABORTING
        print("[CMD] Estado: ABORTING — ABORT enviado.")
        # Retorna imediatamente ao IDLE (sem lógica adicional necessária)
        self._enter_idle()

    # ─────────────────────────────────────────
    #  HANDLERS DE CADA ESTADO
    # ─────────────────────────────────────────
    def _handle_idle(self):
        # Apenas aguarda o início do armamento quando o botão é pressionado.
        if self._button_pressed():
            self._enter_arming()

    def _handle_arming(self):
        # Se o botão for solto antes de 5 segundos, o processo é cancelado.
        if not self._button_pressed():
            print("[CMD] Botão solto antes dos 5 s — cancelando.")
            self._enter_idle()
            return

        # Enquanto o botão estiver pressionado, pisca LED amarelo e buzzer.
        self._blink_tick()

        elapsed = utime.ticks_diff(utime.ticks_ms(), self._press_start_ms)
        remaining = max(0, (HOLD_REQUIRED_MS - elapsed) // 1000)

        # Exibe uma atualização de tempo a cada segundo.
        if elapsed // 1000 != (elapsed - 50) // 1000:
            print(f"[CMD] Armando... {remaining} s restantes.")

        # Se o tempo mínimo for atingido, inicia a transmissão.
        if elapsed >= HOLD_REQUIRED_MS:
            self._enter_transmitting()

    def _handle_transmitting(self):
        # Se o botão soltar durante a transmissão, aborta imediatamente.
        if not self._button_pressed():
            print("[CMD] Botão solto durante transmissão — ABORT.")
            self._enter_aborting()
            return

        now = utime.ticks_ms()

        # Reenvia o comando de armamento periodicamente.
        if utime.ticks_diff(now, self._last_tx_ms) >= RETRANSMIT_MS:
            self._last_tx_ms = now
            self.lora.send(MSG_ARM)

        # Verifica se o receptor devolveu o ACK.
        incoming = self.lora.receive()
        if incoming == MSG_ACK:
            self._enter_confirmed()
            return

        # Se não receber ACK dentro do tempo, reinicia a janela de espera.
        if utime.ticks_diff(now, self._tx_start_ms) >= ACK_TIMEOUT_MS:
            print("[CMD] Timeout aguardando ACK — continuando a transmitir.")
            self._tx_start_ms = now

    def _handle_confirmed(self):
        # Após confirmação, retornar a IDLE apenas quando o botão for solto.
        if not self._button_pressed():
            print("[CMD] Botão solto após confirmação — retornando ao IDLE.")
            self.lora.send(MSG_ABORT)   # sinaliza encerramento à base remota
            self._enter_idle()

    # ─────────────────────────────────────────
    #  LOOP PRINCIPAL
    # ─────────────────────────────────────────
    def run(self):
        # Exibe cabeçalho de inicialização do sistema.
        print("=" * 60)
        print("  ESTAÇÃO DE COMANDO — Sistema de Ignição LoRa 433 MHz")
        print("=" * 60)
        self._enter_idle()

        while True:
            if self.state == State.IDLE:
                self._handle_idle()
            elif self.state == State.ARMING:
                self._handle_arming()
            elif self.state == State.TRANSMITTING:
                self._handle_transmitting()
            elif self.state == State.CONFIRMED:
                self._handle_confirmed()

            # Pequena pausa para manter a execução responsiva sem bloquear demais.
            utime.sleep_ms(10)


# ╔══════════════════════════════════════════════════════════════╗
# ║                    PONTO DE ENTRADA                         ║
# ╚══════════════════════════════════════════════════════════════╝
if __name__ == "__main__":
    station = CommandStation()
    station.run()

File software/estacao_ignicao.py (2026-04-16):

# ==============================================================================
#   ESTAÇÃO DE IGNIÇÃO DE FOGUETES - RECEPTOR/ATUADOR # type: ignore
#   Hardware: Raspberry Pi Pico + LoRa SX1278 (433 MHz) # type: ignore
#   Protocolo: SPI
# ==============================================================================
#
#   MAPEAMENTO DE PINOS: # type: ignore
#   ─────────────────────────────────────────────────────
#   SX1278 (LoRa)         Pico
#   ─────────────────────────────────────────────────────
#   SCK        ──────────  GP2 - 4
#   MOSI       ──────────  GP3 - 5
#   MISO       ──────────  GP0 - 1
#   NSS (CS)   ──────────  GP1 - 2
#   RESET      ──────────  GP4 - 6
#   ─────────────────────────────────────────────────────
#   Relê               ──  GP26   (Ativo em ALTO - NAO INVERTER)
#   Buzzer             ──  GP19
#   LED Vermelho       ──  GP12   (Contagem / Erro)
#   LED Amarelo        ──  GP11   (Conectado / Ativo)
#   Botão Energia      ──  GP20   (Pull-down interno, ativo em ALTO)
#   ─────────────────────────────────────────────────────
#
#   LÓGICA DE SEGURANÇA:
#   - O Relê é inicializado em BAIXO e SÓ é ativado após
#     5 segundos contínuos de sinal "ARM_CONFIRMED".
#   - Qualquer interrupção do sinal (>500 ms) ou recepção
#     de "ABORT" reseta imediatamente a contagem.
#   - O sistema usa ticks_ms() para temporização não-bloqueante,
#     garantindo que o rádio continue sendo lido durante a contagem.
#   - O botão de energia deve ser pressionado após o boot para
#     liberar o teste de conexão e o loop principal.
# ==============================================================================

import utime
from machine import Pin, SPI

# =============================================================================
#  DEFINIÇÃO DE PINOS
# =============================================================================

SPI_SCK  = 4
SPI_MOSI = 5
SPI_MISO = 1

# Pinos de controle do SX1278
LORA_CS    = Pin(2, Pin.OUT, value=1)  # NSS: HIGH = modulo desmarcado
LORA_RESET = Pin(6, Pin.OUT, value=1)  # RESET: LOW por 10ms para resetar

# Atuadores e Indicadores
PIN_RELE         = Pin(31, Pin.OUT, value=0)  # Rele: garantido BAIXO no boot
PIN_BUZZER       = Pin(25, Pin.OUT, value=0)
PIN_LED_VERMELHO = Pin(16, Pin.OUT, value=0)  # Vermelho: Pisca em contagem/erro, ON ignicao
PIN_LED_AMARELO  = Pin(15, Pin.OUT, value=0)  # Amarelo: ON quando conectado/ativo

# Botão de energia (pull-down interno; pressionar = nível ALTO)
PIN_BOTAO_ENERGIA = Pin(26, Pin.IN, Pin.PULL_DOWN)

# =============================================================================
#  ENDERECOS DE REGISTRADORES DO SX1278
# =============================================================================

REG_FIFO            = 0x00
REG_OP_MODE         = 0x01
REG_FRF_MSB         = 0x06
REG_FRF_MID         = 0x07
REG_FRF_LSB         = 0x08
REG_PA_CONFIG       = 0x09
REG_LNA             = 0x0C
REG_FIFO_ADDR_PTR   = 0x0D
REG_FIFO_TX_BASE    = 0x0E
REG_FIFO_RX_BASE    = 0x0F
REG_FIFO_RX_CURRENT = 0x10
REG_IRQ_FLAGS       = 0x12
REG_RX_NB_BYTES     = 0x13
REG_MODEM_CONFIG1   = 0x1D
REG_MODEM_CONFIG2   = 0x1E
REG_PREAMBLE_MSB    = 0x20
REG_PREAMBLE_LSB    = 0x21
REG_PAYLOAD_LENGTH  = 0x22
REG_MODEM_CONFIG3   = 0x26
REG_SYNC_WORD       = 0x39
REG_DIO_MAPPING1    = 0x40
REG_VERSION         = 0x42

# Modos de operacao do SX1278
MODE_SLEEP   = 0x00
MODE_STDBY   = 0x01
MODE_TX      = 0x03
MODE_RX_CONT = 0x05
MODE_LORA    = 0x80  # Bit 7 = 1 habilita modo LoRa

# Mascaras de flag de interrupcao (registrador IRQ_FLAGS)
IRQ_RX_DONE = 0x40  # Pacote recebido com sucesso
IRQ_TX_DONE = 0x08  # Transmissao concluida

# =============================================================================
#  INICIALIZACAO DO BARRAMENTO SPI
# =============================================================================

spi = SPI(0,
          baudrate=10_000_000,
          polarity=0,
          phase=0,
          sck=Pin(SPI_SCK),
          mosi=Pin(SPI_MOSI),
          miso=Pin(SPI_MISO))

# =============================================================================
#  FUNCOES SPI DE BAIXO NIVEL
# =============================================================================

def _spi_write(reg, value):
    # Bit 7 = 1 indica operacao de escrita no SX1278
    LORA_CS.value(0)
    spi.write(bytes([reg | 0x80, value]))
    LORA_CS.value(1)

def _spi_read(reg):
    # Bit 7 = 0 indica operacao de leitura
    LORA_CS.value(0)
    spi.write(bytes([reg & 0x7F]))
    result = spi.read(1)
    LORA_CS.value(1)
    return result[0]

def _spi_read_buf(reg, length):
    # Leitura de multiplos bytes consecutivos do FIFO
    LORA_CS.value(0)
    spi.write(bytes([reg & 0x7F]))
    result = spi.read(length)
    LORA_CS.value(1)
    return result

# =============================================================================
#  DRIVER DO MODULO LORA SX1278
# =============================================================================

def lora_reset():
    # Pulso de reset por hardware conforme datasheet do SX1278 (minimo 100us)
    LORA_RESET.value(0)
    utime.sleep_ms(10)
    LORA_RESET.value(1)
    utime.sleep_ms(10)

def lora_init(frequency=433_000_000):
    # Inicializa o SX1278 em modo LoRa
    lora_reset()

    # Verifica identidade do chip: SX1276/77/78/79 retornam 0x12
    version = _spi_read(REG_VERSION)
    if version != 0x12:
        return False  # SPI com defeito ou modulo nao conectado

    # Entra em Sleep com LoRa ativado
    _spi_write(REG_OP_MODE, MODE_LORA | MODE_SLEEP)
    utime.sleep_ms(10)

    # Calcula e grava os registradores de frequencia
    frf = int((frequency * (1 << 19)) / 32_000_000)
    _spi_write(REG_FRF_MSB, (frf >> 16) & 0xFF)
    _spi_write(REG_FRF_MID, (frf >> 8)  & 0xFF)
    _spi_write(REG_FRF_LSB,  frf        & 0xFF)

    # Potencia de saida via PA_BOOST: 17 dBm
    _spi_write(REG_PA_CONFIG, 0x8F)

    # LNA: ganho maximo automatico com boost para banda HF (433 MHz)
    _spi_write(REG_LNA, 0x23)

    # Modem Config 1: BW=125kHz, CodingRate=4/5, Header explicito
    _spi_write(REG_MODEM_CONFIG1, 0x72)

    # Modem Config 2: SF=7, CRC habilitado
    _spi_write(REG_MODEM_CONFIG2, 0x74)

    # Modem Config 3: AGC automatico habilitado
    _spi_write(REG_MODEM_CONFIG3, 0x04)

    # Preambulo de 8 simbolos (minimo recomendado)
    _spi_write(REG_PREAMBLE_MSB, 0x00)
    _spi_write(REG_PREAMBLE_LSB, 0x08)

    # Sync Word privado: 0x12
    _spi_write(REG_SYNC_WORD, 0x12)

    # Enderecos base do FIFO para TX e RX (sem sobreposicao)
    _spi_write(REG_FIFO_TX_BASE, 0x00)
    _spi_write(REG_FIFO_RX_BASE, 0x00)

    # Volta ao Standby antes de iniciar recepcao
    _spi_write(REG_OP_MODE, MODE_LORA | MODE_STDBY)
    utime.sleep_ms(10)

    return True

def lora_receive_mode():
    _spi_write(REG_OP_MODE, MODE_LORA | MODE_RX_CONT)

def lora_packet_available():
    flags = _spi_read(REG_IRQ_FLAGS)
    return bool(flags & IRQ_RX_DONE)
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

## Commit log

2026-03-04 Organizar arquivos de hardware: criar pasta fritzing e schematics, atualizar README
    [ESTAÇAO DE COMANDO.fzz]
2026-03-04 Adicionar arquivo Fritzing da caixa de ignição
    [CAIXA DE IGNIÇAO.fzz]
2026-03-16 Fix README image paths
    [CAIXA DE IGNIÇAO.fzz]
2026-03-16 Update hardware images and README links
    [ESTAÇAO DE COMANDO.fzz]
2026-03-16 Preserve fritzing file changes
    [CAIXA DE IGNIÇAO.fzz, ESTAÇAO DE COMANDO.fzz, ESTAÇÃO DE IGNIÇÃO.fzz]
2026-03-16 Document schematic image assets
2026-03-22 Atualiza componentes e imagens no README do hardware, corrigindo referências e adicionando informações sobre o módulo TP4056.
    [ESTAÇAO DE COMANDO.fzz, ESTAÇÃO DE IGNIÇÃO.fzz]
2026-03-22 Atualiza a lista de componentes no README, renomeando "MOSFET/Relé" para "Relé" e removendo o link do módulo TP4056.
2026-03-22 modelos em 3d adcionados
    [lado1.stl, lado2.stl, tampabaixo.stl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]
2026-03-22 Atualiza README do hardware: corrige referências do módulo LoRa, ajusta quantidade de LEDs e modifica descrição do relé/MOSFET.
2026-03-22 chore(hardware): atualizar esquematicos, README e modelos 3D
    [lado 2.stl, lado1.stl, lado2.stl]
2026-03-22 corrige nomes de arquivos de esquemas no README
2026-03-25 chore(hardware): substituir modelos 3D STL por arquivos STEP
    [lado 2.stl, lado1.step, lado1.stl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]
2026-03-29 Versão 1 - Estação de Comando/Ignição
2026-04-10 Removes outdated 3D model STEP files
    Deletes obsolete hardware 3D model files to reduce repository size and prevent confusion with current mechanical designs. Ensures only up-to-date CAD assets are tracked.
    [CAIXA.step, TAMPABAIXO.step, TAMPACIMA.step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]
2026-04-16 Refactor code structure for improved readability and maintainability
    [CAIXA.step, caixapart1.step, caixapart2.step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]
